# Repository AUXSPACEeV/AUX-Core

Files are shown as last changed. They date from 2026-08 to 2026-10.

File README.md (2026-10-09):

# `AUX-Core`

> Core/Sensor PCB of the Auxspace Avionics stack, built around an ESP32-S3-WROOM-1.

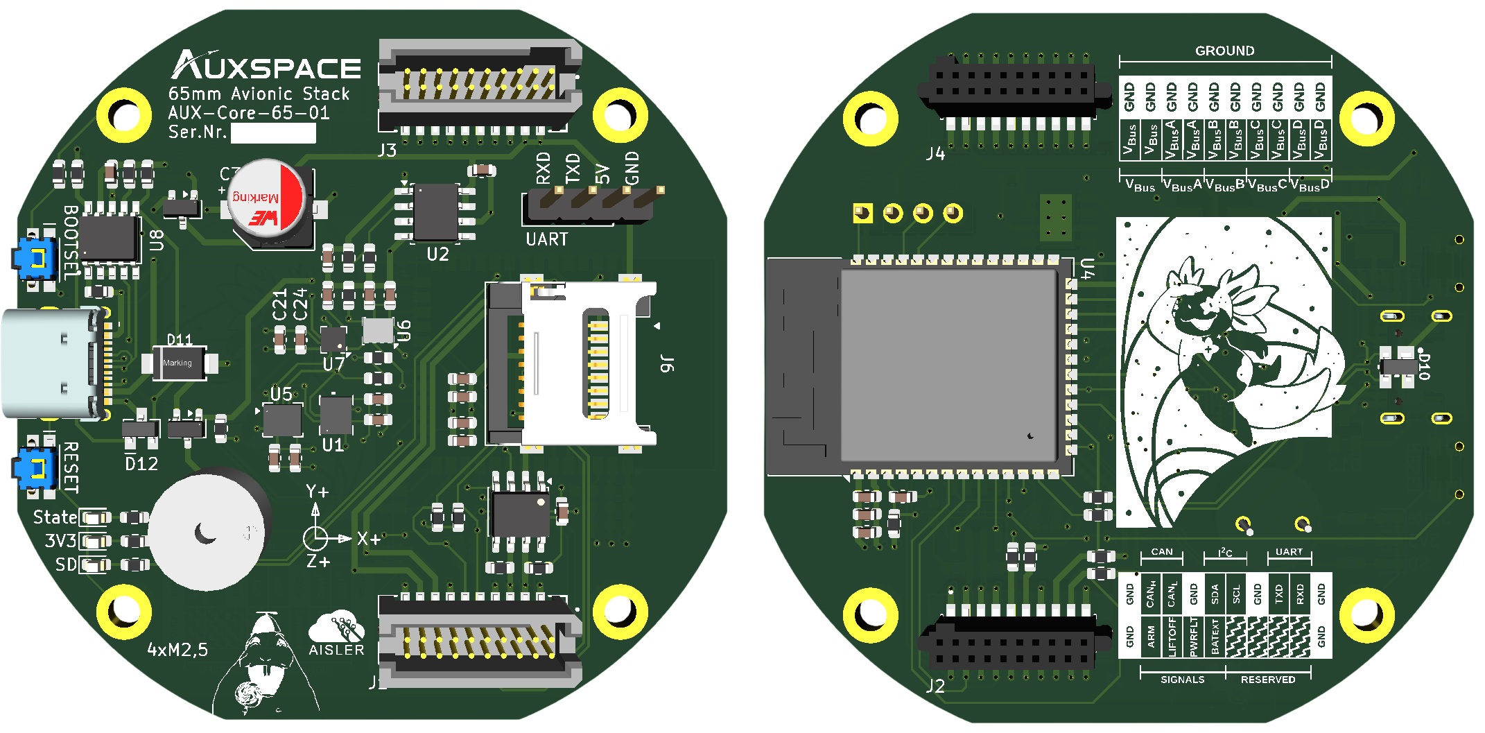
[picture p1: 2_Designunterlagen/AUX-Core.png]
pcb_cover,png


AUX-Core is our first stackable flight computer.
It operates on a powerful ESP32S3 MCU with sensors for attitude tracking,
9V USB Power Delivery or an external Power source and can interface
with other Auxspace Avionics stack components, such as
[AUX-Pwr](https://github.com/AUXSPACEeV/AUX-Pwr) or
[AUX-Tel](https://github.com/AUXSPACEeV/AUX-Tel).

## Features

* **Barometer** DPS310/DPS368 for altitude computation
* **IMU** STM LSM6DSO32x for acceleration and rotation data
* **High-G accelerometer** STM LSM6DSV320XTR (±320 g) when things get tough
* **Magnetometer** STM LIS3MDL for attitude reference
* **Buzzer** for easier commissioning and recovery
* **CAN bus** (TCAN334) for communication with the other stack PCBs
* **µSD card** for logging
* **USB-C with 9 V Power Delivery** (CH224A sink) for programming, debugging and supply
* **Stack connector** Samtec TFM-110-02-S-D-A / SFM-110-02-L-D-A for the avionics stack
* **Status LEDs** for power, SD activity and board state

## Stack connector

The board carries a mating Samtec pin/socket pair (2x10, 1.27 mm), so Core boards and
expansion PCBs stack directly on top of each other. The connector routes the switched and
unswitched VBus rails, CAN, I²C, UART and the ARM signal through the stack.

## Power supply

The board is supplied over USB-C. The CH224A PD sink negotiates 9 V from the charger; the
on-board TPS7B8601 regulator derives the 3V3 rail from it. VBus is distributed to the stack
both directly and through the switched rails.

## Programming

The ESP32-S3 is programmed via USB-C or the UART connection.
To enter download mode, press and hold BOOTSEL at startup.

## Repository layout

| Folder | Content |
| --- | --- |
| [`1_Blockschaltbild`](./1_Blockschaltbild) | Block diagrams |
| [`2_Designunterlagen`](./2_Designunterlagen) | Pin maps, calculations and design documents |
| [`3_Elektronik`](./3_Elektronik) | KiCad project, symbols, footprints and 3D models  |
| [`4_Simulationen`](./4_Simulationen) | LTspice simulations |
| [`5_Tests`](./5_Tests) | Test results and oscillograms |
| [`6_Export-Fertigungsdaten`](./6_Export-Fertigungsdaten) | Manufacturing data, BOMs, schematics and STEP files |

## License

Hardware is released under the CERN Open Hardware Licence Version 2 - Permissive,
see [`LICENSE`](./LICENSE).

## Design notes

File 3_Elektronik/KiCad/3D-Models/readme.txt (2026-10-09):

Notes:
 
1. All drill sizes are the maximum size provided by the manufacture (as required to calculate the minimum pad size).
2. All dimensions in building footprints are the maximum (including any tolerance) as defined by the manufacturer with the exception of row pitch (which is always nominal).  If only the normal sizing is provided we will input that dimension in mils, rounded to the nearest mil per our standards.
3. Slots are currently identified as entities describing the size of the slot (arcs, lines, etc.) on the board outline layer.  The extremities are identified with a via at each end.  These slots will either need to be:
	a. identified and dimensioned on your fabrication document
	b. or they will need to be converted to slots (assuming the targeted tool has a slot capability) using the process defined in your cad tool for identifying a padstack as a slot.  
		i. Typically this is only capable of a width and length of the slot and a size of the mill radius that creates the slot.  
		ii. Choosing to use the native tool slots will require removing entities on the board outline and the associated pads in the footprint.

Attribution:

Symbols, footprints and 3D models of Würth Elektronik parts (files named *Wurth*, *Würth*, *Wuerth*, WE-* and
the matching entries in AUXSPACE.kicad_sym / AUXSPACE.pretty, e.g. the WS-TASU, WS-TASV, WR-CRD,
WR-USB, WR-WTB, WCAP-ASLL and WE-TVS libraries) are © Würth Elektronik eiSos GmbH & Co. KG, https://www.we-online.com,
and are licensed under the Creative Commons Attribution-ShareAlike 4.0 International License
(https://creativecommons.org/licenses/by-sa/4.0/). Changes made for this project: converted to the current KiCad file
format, merged into the AUXSPACE libraries, and footprint/3D-model paths and footprint links adapted.

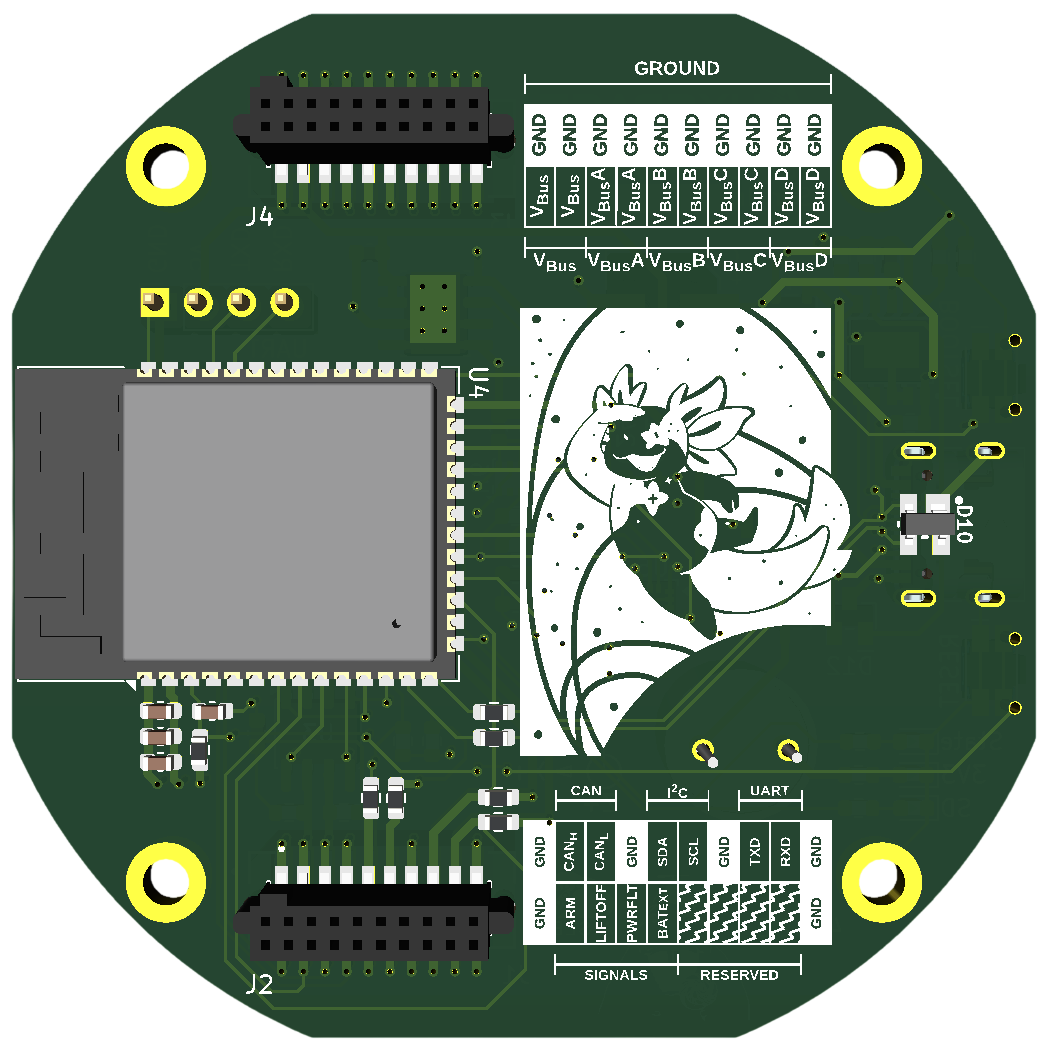
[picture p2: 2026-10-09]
6_Export-Fertigungsdaten/rev-01/AUXSPACE_core_pcb_back.png

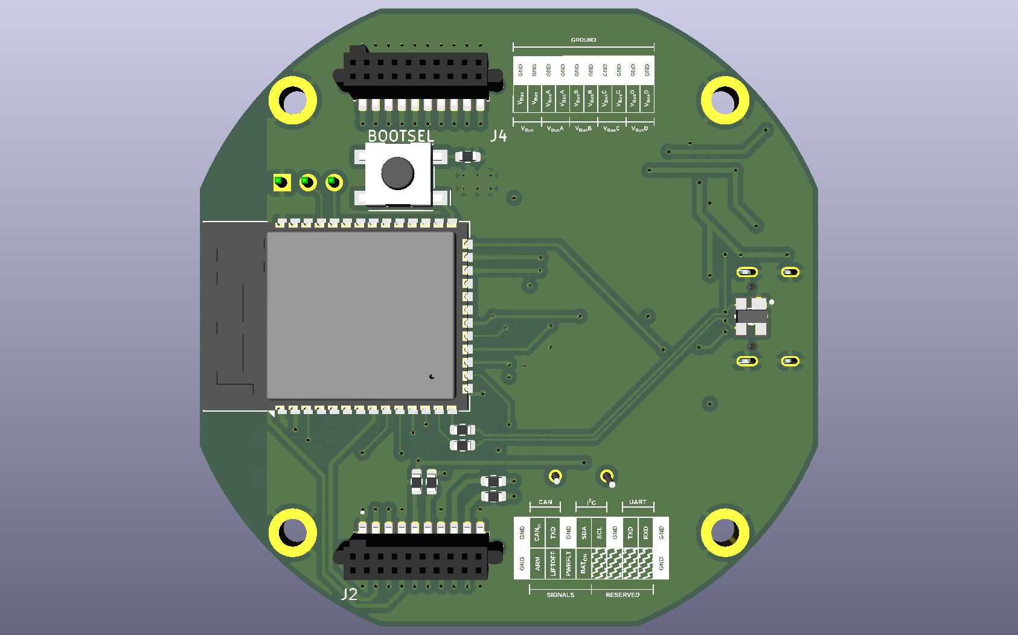
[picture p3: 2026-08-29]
6_Export-Fertigungsdaten/rev-cansta-alpha/AUXSPACE_core_pcb_back.png

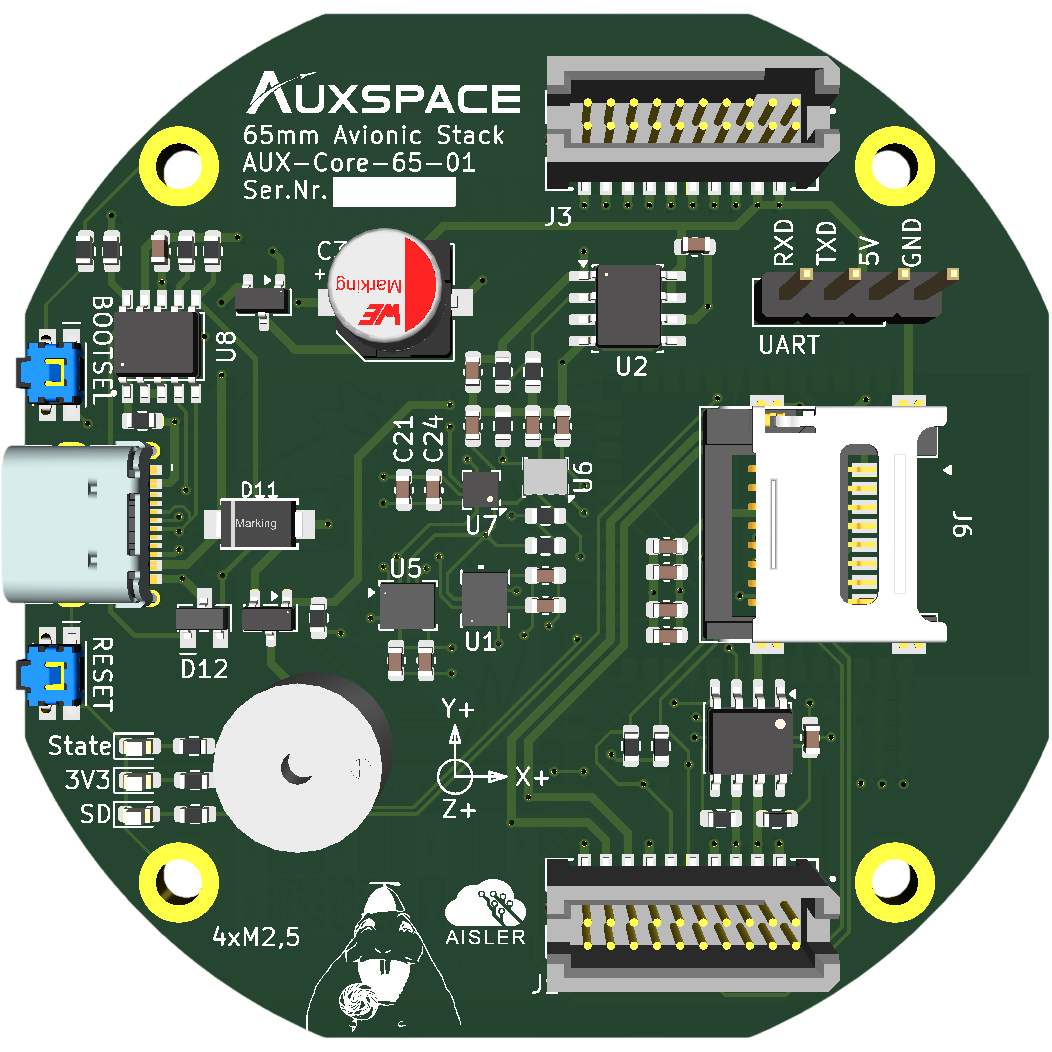
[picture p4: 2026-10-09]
6_Export-Fertigungsdaten/rev-01/AUXSPACE_core_pcb_front.png

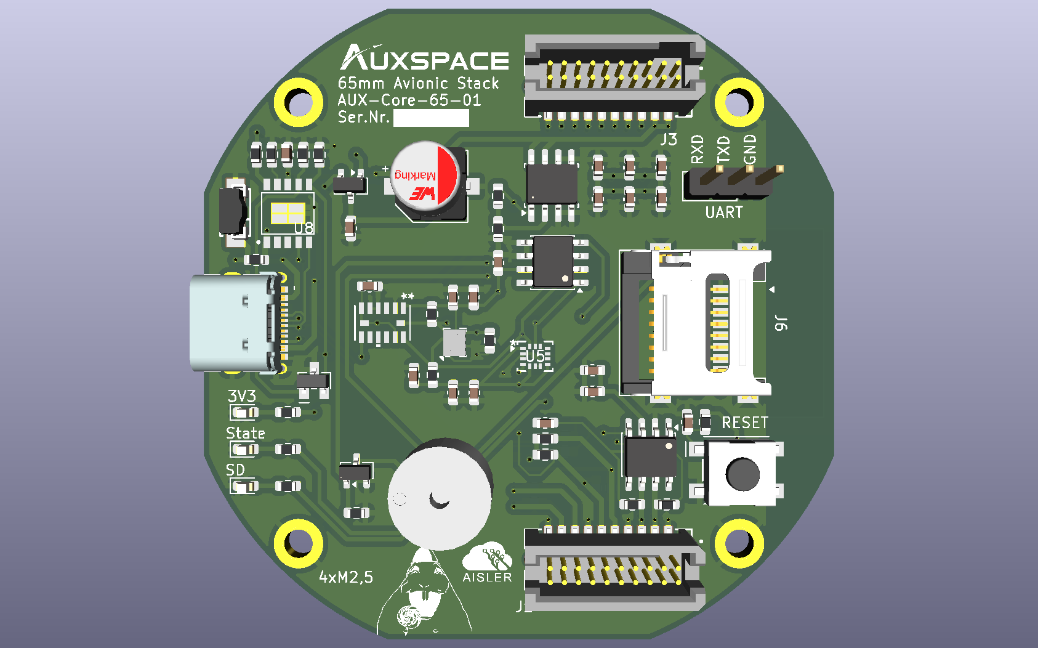
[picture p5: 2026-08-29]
6_Export-Fertigungsdaten/rev-cansta-alpha/AUXSPACE_core_pcb_front.png

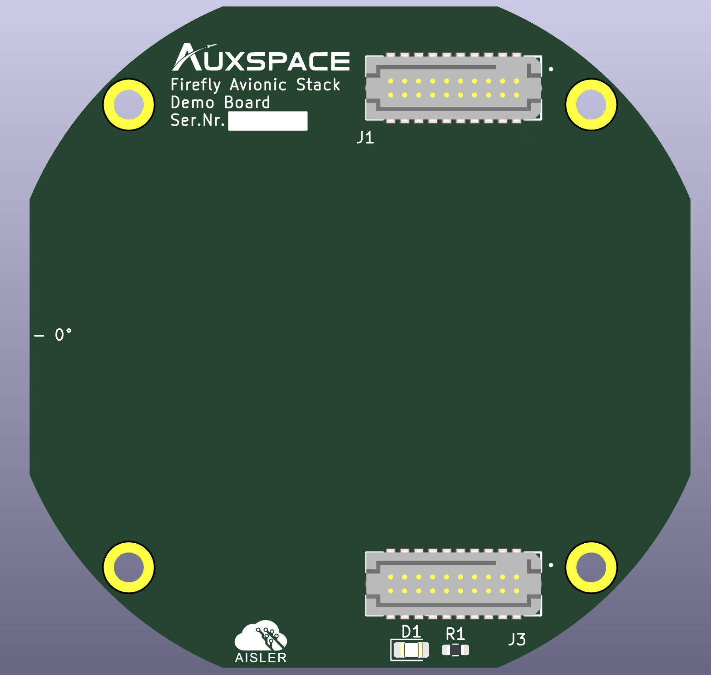
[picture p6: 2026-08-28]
3_Elektronik/KiCad/meta/brd.png

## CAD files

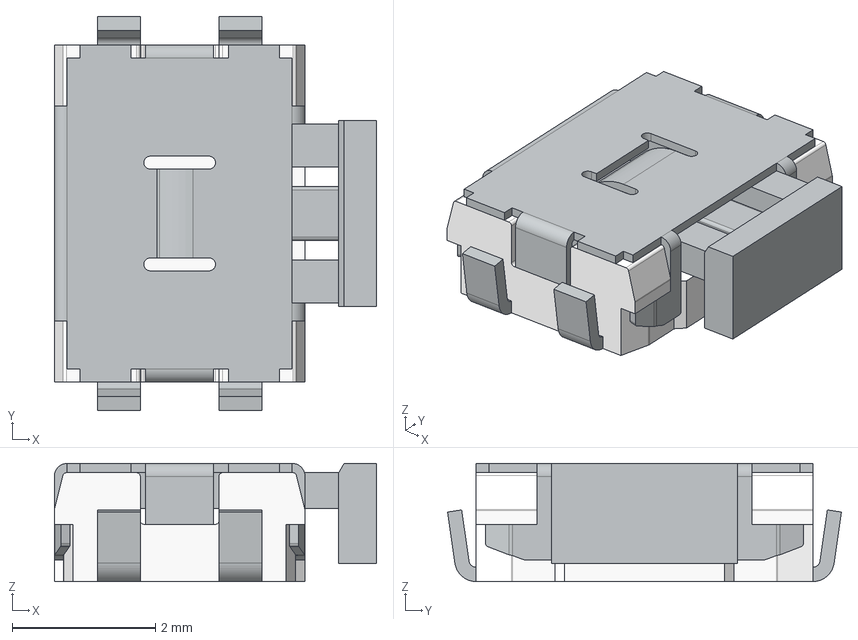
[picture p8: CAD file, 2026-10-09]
3_Elektronik/KiCad/3D-Models/SW_Wurth_WS-TASU_4343X30458XX.step
4.50 x 5.50 x 1.65 mm

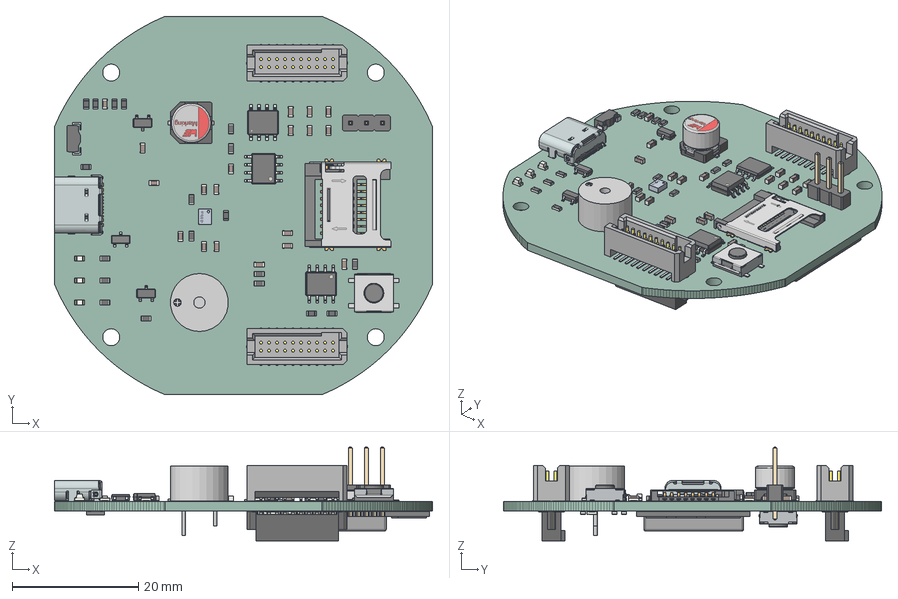
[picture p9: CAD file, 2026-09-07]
6_Export-Fertigungsdaten/rev-01/Aux-core.step
60.0 x 60.0 x 14.9 mm
R_0603_1608Metric x 26
C_0603_1608Metric x 19
CP_Wurth_WCAP-ASLL-D6.3L5.5
1_transformed
LED_0603_1608Metric x 3
SOT-23 x 2
SOIC-8_3.9x4.9mm_P1.27mm x 2
PinHeader_1x03_P254mm_Vertical
SMAJ-ALL
WST-0906T v2
Texas_HTSOP-8-1EP_3.9x4.9mm_P1.27mm_EP2.95x4.9mm_Mask2.4x3.1mm_ ThermalVias
693072010801_PIN x 8
693072010801_PATTE x 3
693072010801_CACHE
693072010801_PATTE_SPE
SW_Wurth_WS-TASV_430481025816 x 2
CADSOFTTOOLS 2.1
CADSOFTTOOLS 2.2
CADSOFTTOOLS 2.3
CADSOFTTOOLS 2.4
CADSOFTTOOLS 2.5
CADSOFTTOOLS 2.6
CADSOFTTOOLS 2.7
CADSOFTTOOLS 2.8
CADSOFTTOOLS 2.9
CADSOFTTOOLS 2.10
CADSOFTTOOLS 2.11
CADSOFTTOOLS 2.12
CADSOFTTOOLS 2.13
CADSOFTTOOLS 2.14
CADSOFTTOOLS 2.15
CADSOFTTOOLS 2.16
CADSOFTTOOLS 2.17
CADSOFTTOOLS 2.18
CADSOFTTOOLS 2.19
CADSOFTTOOLS 2.20
CADSOFTTOOLS 2.21
CADSOFTTOOLS 2.22
CADSOFTTOOLS 2.23
CADSOFTTOOLS 2.24
CADSOFTTOOLS 2.25
CADSOFTTOOLS 2.26
CADSOFTTOOLS 2.27
CADSOFTTOOLS 2.28
CADSOFTTOOLS 2.29
CADSOFTTOOLS 2.30
CADSOFTTOOLS 2.31
CADSOFTTOOLS 2.32
CADSOFTTOOLS 2.33
CADSOFTTOOLS 2.34
CADSOFTTOOLS 2.35
CADSOFTTOOLS 2.36
CADSOFTTOOLS 2.37
CADSOFTTOOLS 2.38
CADSOFTTOOLS 2.39
CADSOFTTOOLS 2.40
CADSOFTTOOLS 2.41
CADSOFTTOOLS 2.42
CADSOFTTOOLS 2.43
CADSOFTTOOLS 2.44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

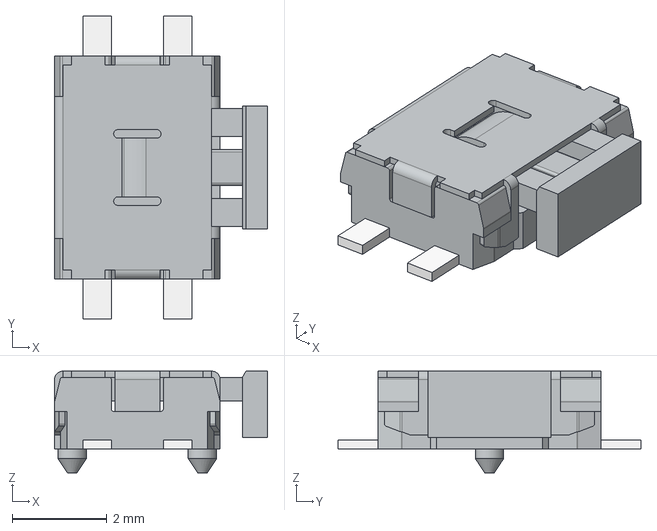
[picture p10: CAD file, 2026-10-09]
3_Elektronik/KiCad/3D-Models/SW_Wurth_WS-TASU_4363X10458XX.step
4.50 x 6.40 x 2.15 mm

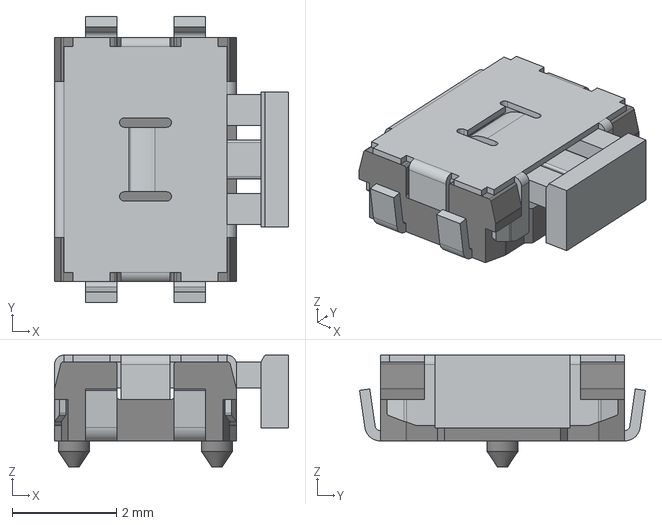
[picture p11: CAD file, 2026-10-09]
3_Elektronik/KiCad/3D-Models/SW_Wurth_WS-TASU_4363X30458XX.step
4.50 x 5.50 x 2.15 mm

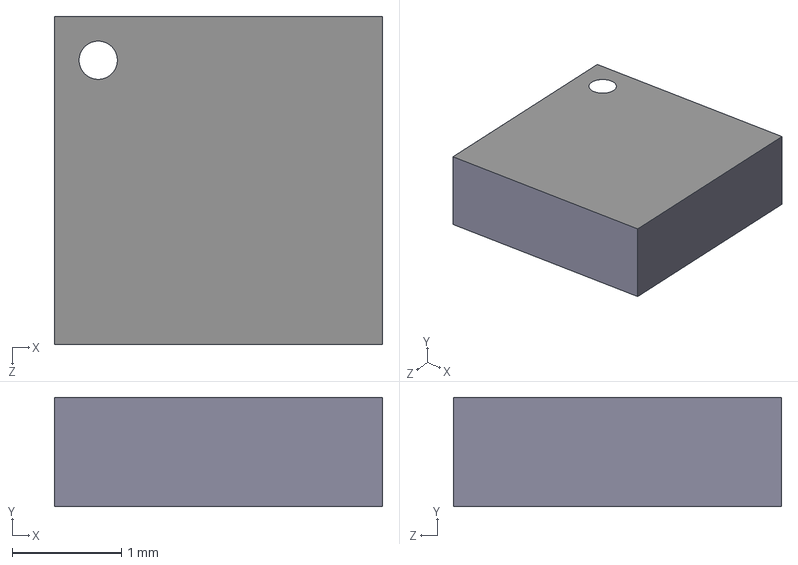
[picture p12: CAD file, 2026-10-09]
3_Elektronik/KiCad/3D-Models/IST8310.step
3.00 x 1.00 x 3.00 mm

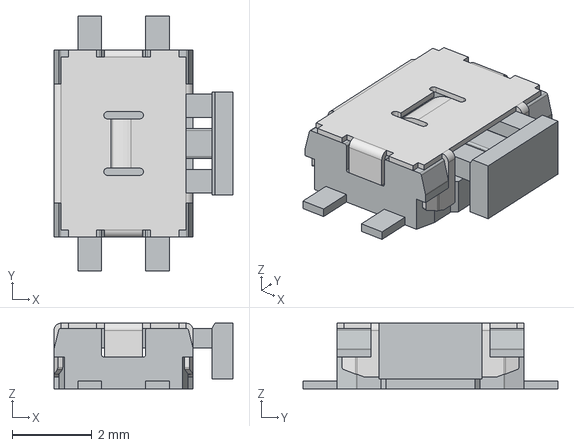
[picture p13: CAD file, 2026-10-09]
3_Elektronik/KiCad/3D-Models/SW_Wurth_WS-TASU_4343X10458XX.step
4.50 x 6.40 x 1.65 mm

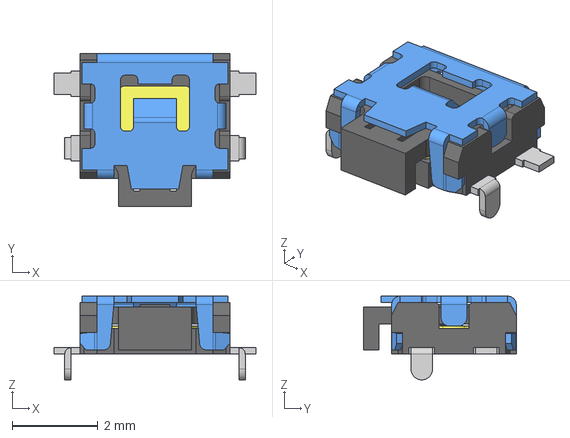
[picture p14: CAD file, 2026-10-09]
3_Elektronik/KiCad/3D-Models/SW_Wurth_WS-TASU_434331013822.step
4.70 x 3.55 x 1.95 mm

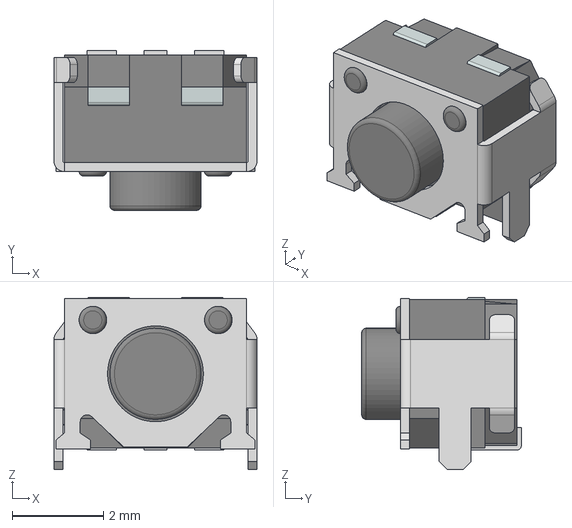
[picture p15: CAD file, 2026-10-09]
3_Elektronik/KiCad/3D-Models/SW_Wurth_WS-TASU_436333033816.step
4.45 x 3.50 x 3.78 mm

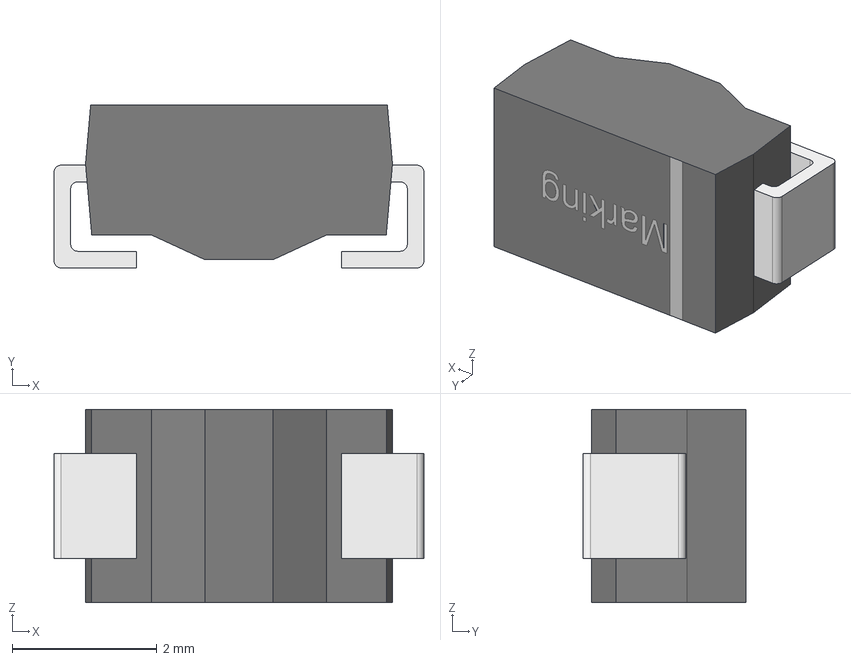
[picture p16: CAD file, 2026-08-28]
3_Elektronik/KiCad/3D-Models/WE-TVS_SMAJ22A.stp
5.11 x 2.25 x 2.67 mm

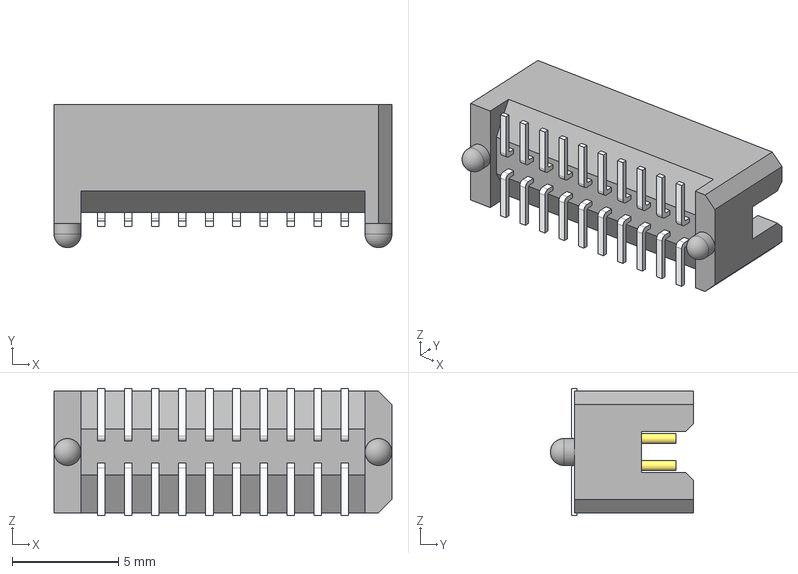
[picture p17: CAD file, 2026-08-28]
3_Elektronik/KiCad/3D-Models/TFM-110-02-S-D-A.stp
15.9 x 6.73 x 5.97 mm
TFM-110-02-L-D-A_terminal
TFM-110-02-L-D-L_pins
TFM-110-02-L-D-S-2_pins

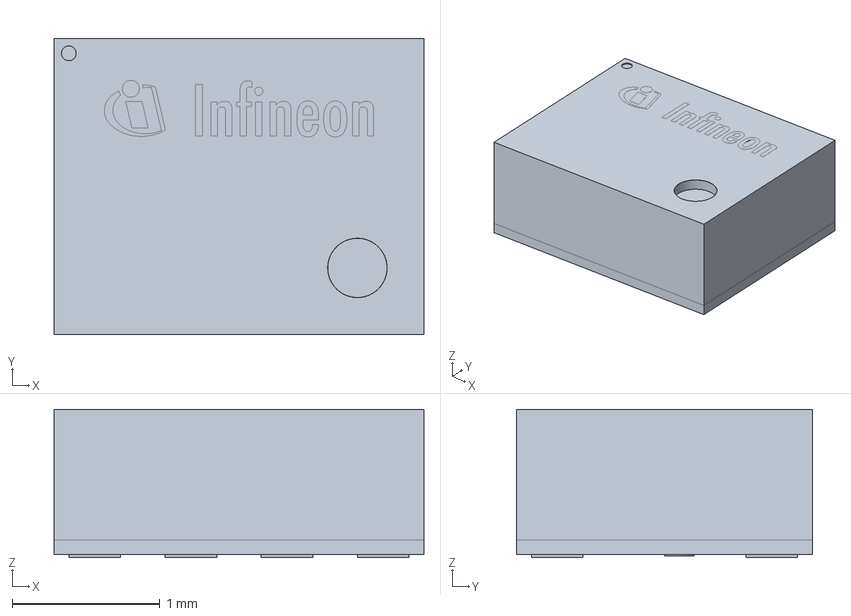
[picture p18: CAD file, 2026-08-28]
3_Elektronik/KiCad/3D-Models/DPS310XTSA1.stp
2.50 x 2.00 x 1.00 mm
CADSOFTTOOLS 2.1
CADSOFTTOOLS 2.2
CADSOFTTOOLS 2.3
CADSOFTTOOLS 2.4
CADSOFTTOOLS 2.5
CADSOFTTOOLS 2.6
CADSOFTTOOLS 2.7
CADSOFTTOOLS 2.8
CADSOFTTOOLS 2.9
CADSOFTTOOLS 2.10
CADSOFTTOOLS 2.11
CADSOFTTOOLS 2.12
CADSOFTTOOLS 2.13
CADSOFTTOOLS 2.14
CADSOFTTOOLS 2.15
CADSOFTTOOLS 2.16
CADSOFTTOOLS 2.17
CADSOFTTOOLS 2.18
CADSOFTTOOLS 2.19
CADSOFTTOOLS 2.20
CADSOFTTOOLS 2.21
CADSOFTTOOLS 2.22
CADSOFTTOOLS 2.23
CADSOFTTOOLS 2.24
CADSOFTTOOLS 2.25
CADSOFTTOOLS 2.26
CADSOFTTOOLS 2.27
CADSOFTTOOLS 2.28
CADSOFTTOOLS 2.29
CADSOFTTOOLS 2.30
CADSOFTTOOLS 2.31
CADSOFTTOOLS 2.32
CADSOFTTOOLS 2.33
CADSOFTTOOLS 2.34
CADSOFTTOOLS 2.35
CADSOFTTOOLS 2.36
CADSOFTTOOLS 2.37
CADSOFTTOOLS 2.38
CADSOFTTOOLS 2.39
CADSOFTTOOLS 2.40
CADSOFTTOOLS 2.41
CADSOFTTOOLS 2.42
CADSOFTTOOLS 2.43
CADSOFTTOOLS 2.44
CADSOFTTOOLS 2.45
CADSOFTTOOLS 2.46
CADSOFTTOOLS 2.47
CADSOFTTOOLS 2.48
CADSOFTTOOLS 2.49
CADSOFTTOOLS 2.50
CADSOFTTOOLS 2.51
CADSOFTTOOLS 2.52
CADSOFTTOOLS 2.53
CADSOFTTOOLS 2.54
CADSOFTTOOLS 2.55
CADSOFTTOOLS 2.56
CADSOFTTOOLS 2.57
CADSOFTTOOLS 2.58
CADSOFTTOOLS 2.59
CADSOFTTOOLS 2.60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

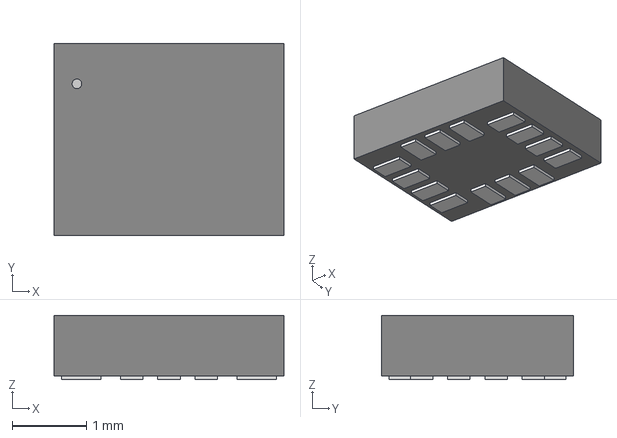
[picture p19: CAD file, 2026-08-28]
3_Elektronik/KiCad/3D-Models/LGA_O32XTR_STM.step
3.10 x 2.59 x 0.866 mm

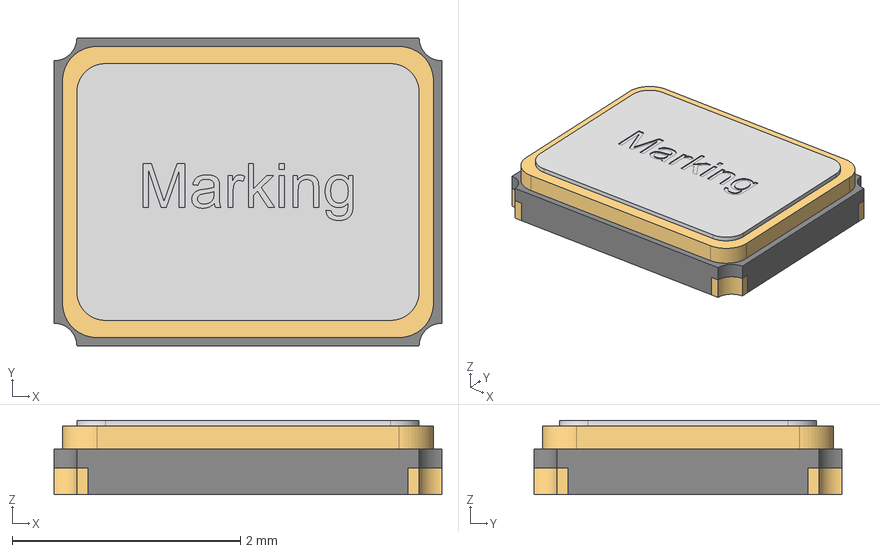
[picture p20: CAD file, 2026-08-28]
3_Elektronik/KiCad/3D-Models/wurth_Crystal_830105420809 (rev1).stp
3.40 x 2.70 x 0.65 mm
Pins
Cover

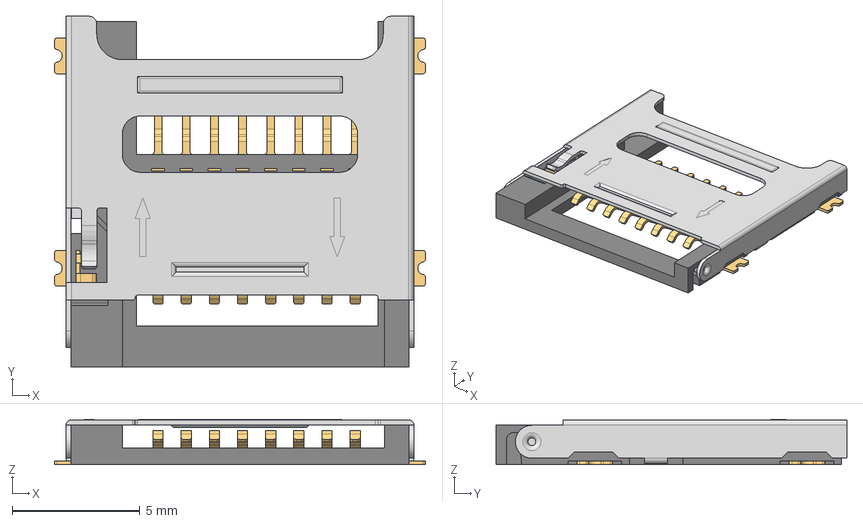
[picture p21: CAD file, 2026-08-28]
3_Elektronik/KiCad/3D-Models/J_Wurth_WR-CRD_693072010801.step
14.5 x 13.7 x 1.77 mm
693072010801_PIN x 8
693072010801_PATTE x 3
693072010801_CACHE
693072010801_PATTE_SPE

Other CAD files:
3_Elektronik/KiCad/3D-Models/J_Wurth_WR-WTB_61900211121.step
3_Elektronik/KiCad/3D-Models/WE-TVS-HS_SOT143-4L_8240136.step
3_Elektronik/KiCad/3D-Models/USBC-Würth_632723100011.step
3_Elektronik/KiCad/3D-Models/Buzzer_WST-0906T.step
3_Elektronik/KiCad/3D-Models/CP_Wurth_WCAP-ASLL-D6.3L5.5.step
3_Elektronik/KiCad/3D-Models/J_Wurth_WR-USB_629722000214.step
3_Elektronik/KiCad/3D-Models/SFM-110-02-L-D-A.stp
3_Elektronik/KiCad/3D-Models/SW_Wurth_WS-TASU_434381035816.step
3_Elektronik/KiCad/3D-Models/SW_Wurth_WS-TASV_430481025816.step
3_Elektronik/KiCad/3D-Models/Texas_HSOP-8_3.9x4.9mm_EP2.95x4.9mm.step
3_Elektronik/KiCad/3D-Models/WE-TVS_824094024_SOT23-3L.step
3_Elektronik/KiCad/3D-Models/WE_693071020811 (rev1).stp

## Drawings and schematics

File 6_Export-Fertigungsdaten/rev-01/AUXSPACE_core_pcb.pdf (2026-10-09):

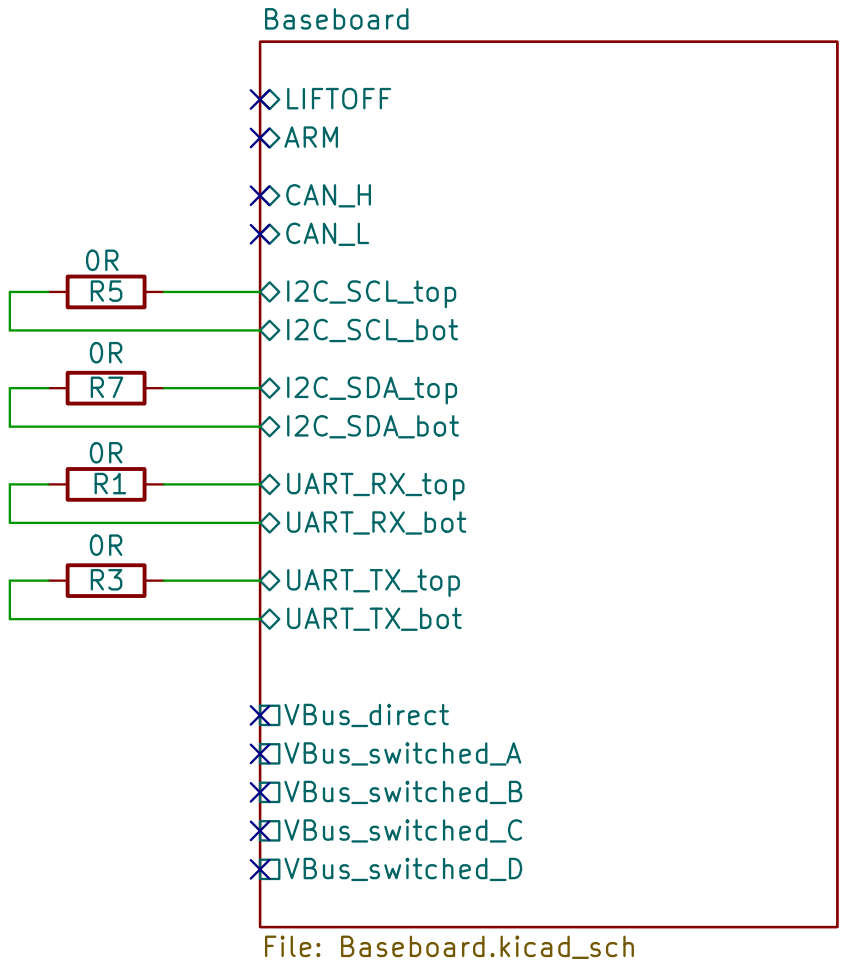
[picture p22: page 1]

Size: A3 | Rev: | F Date:
KiCad E.D.A. 10.0.7 | Id: 1/2

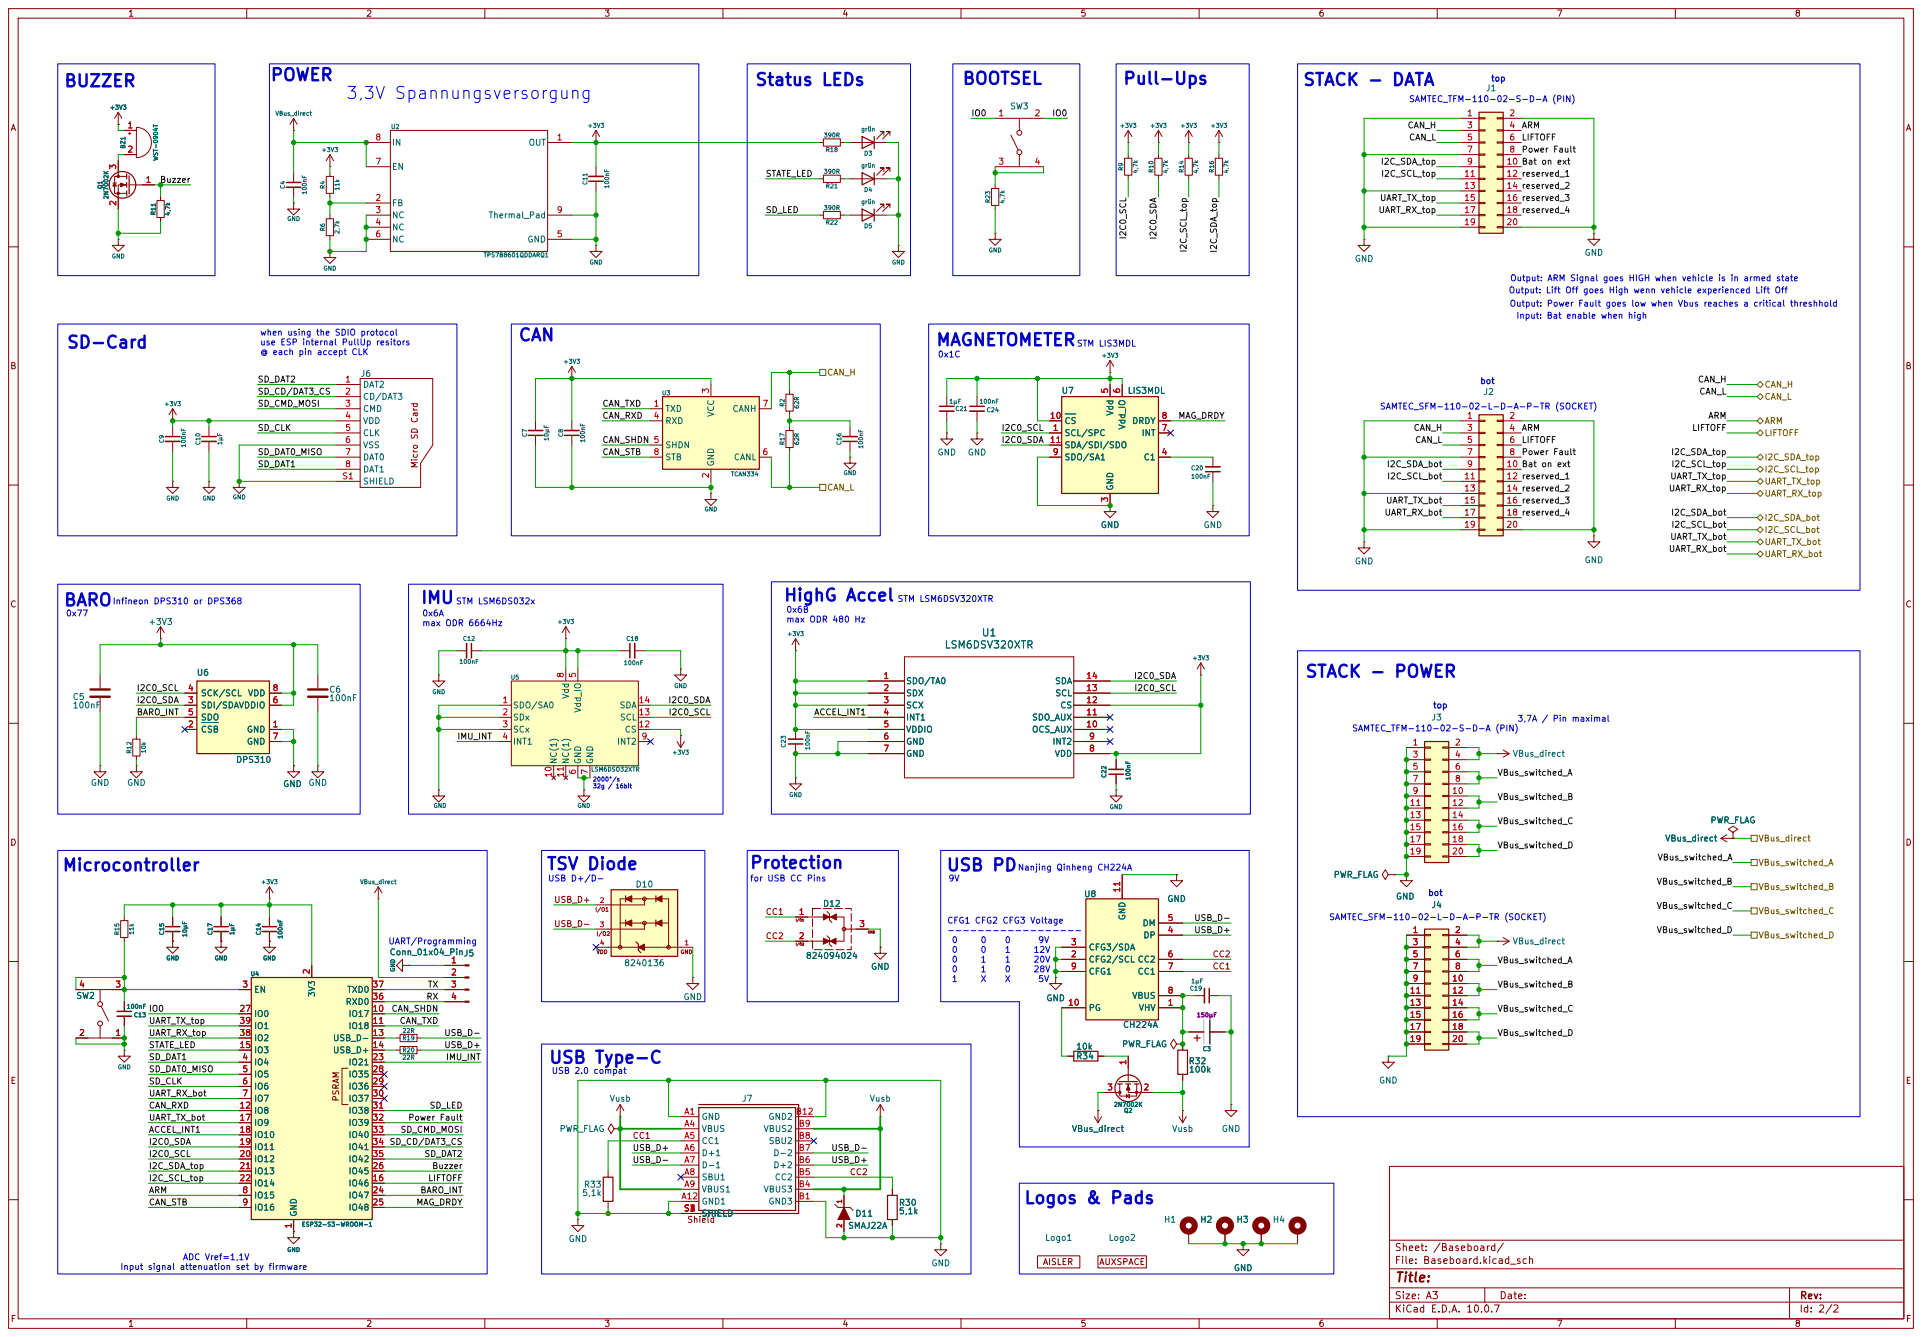
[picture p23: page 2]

when using the SDIO protocol use ESP internal PullUp resitors @ each pin accept CLK BUZZER

Input: Bat enable when high SAMTEC_SFM-110-02-L-D-A-P-TR (SOCKET) STM LIS3MDL BOOTSEL
UART_RX_top CAN_L

Output: ARM Signal goes HIGH when vehicle is in armed state TSV Diode

Output: Power Fault goes low when Vbus reaches a critical threshhold 9V Protection

3,7A / Pin maximal HighG Accel
I2C0_SDA USB_D+

USB PD Nanjing Qinheng CH224A STM LSM6DSV320XTR

9 | 10
11 | 12
13 | 14
15 | 16
17 | 18
19 | 20

7 7 | 8 8
9 9 | 10 10
11 11 | 12 12
13 13 | 14 14
15 15 | 16 16
17 17 | 18 18

Input signal attenuation set by firmware

Size: A3 | Rev: | F Date:
KiCad E.D.A. 10.0.7 | Id: 2/2

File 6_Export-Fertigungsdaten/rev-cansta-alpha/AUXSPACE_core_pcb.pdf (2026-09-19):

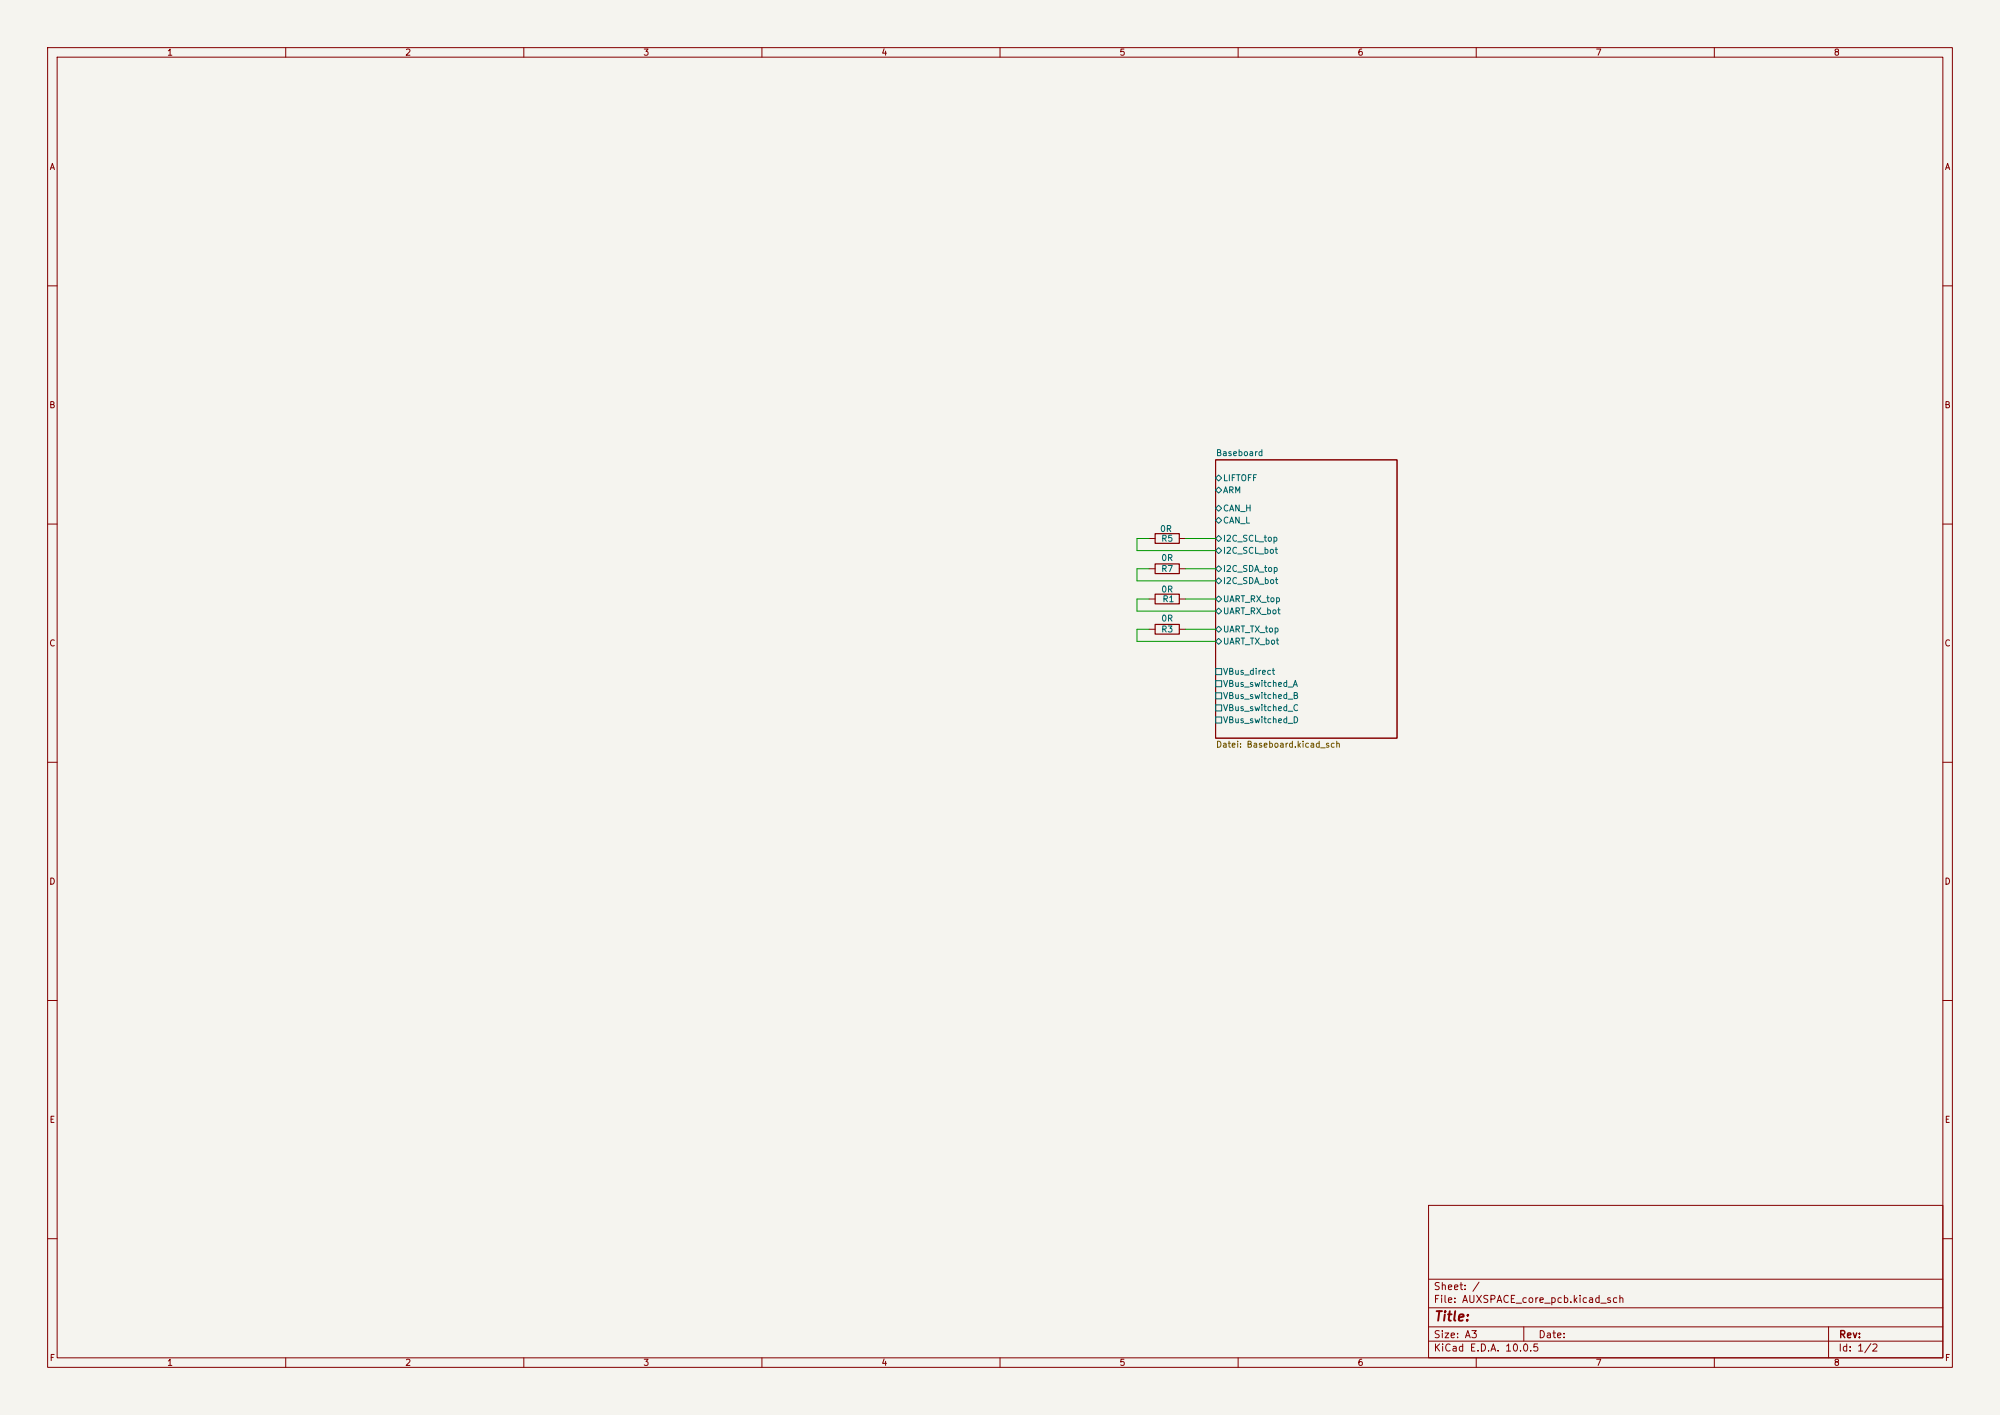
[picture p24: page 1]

Size: A3 | Rev: | F Date:
KiCad E.D.A. 10.0.5 | Id: 1/2

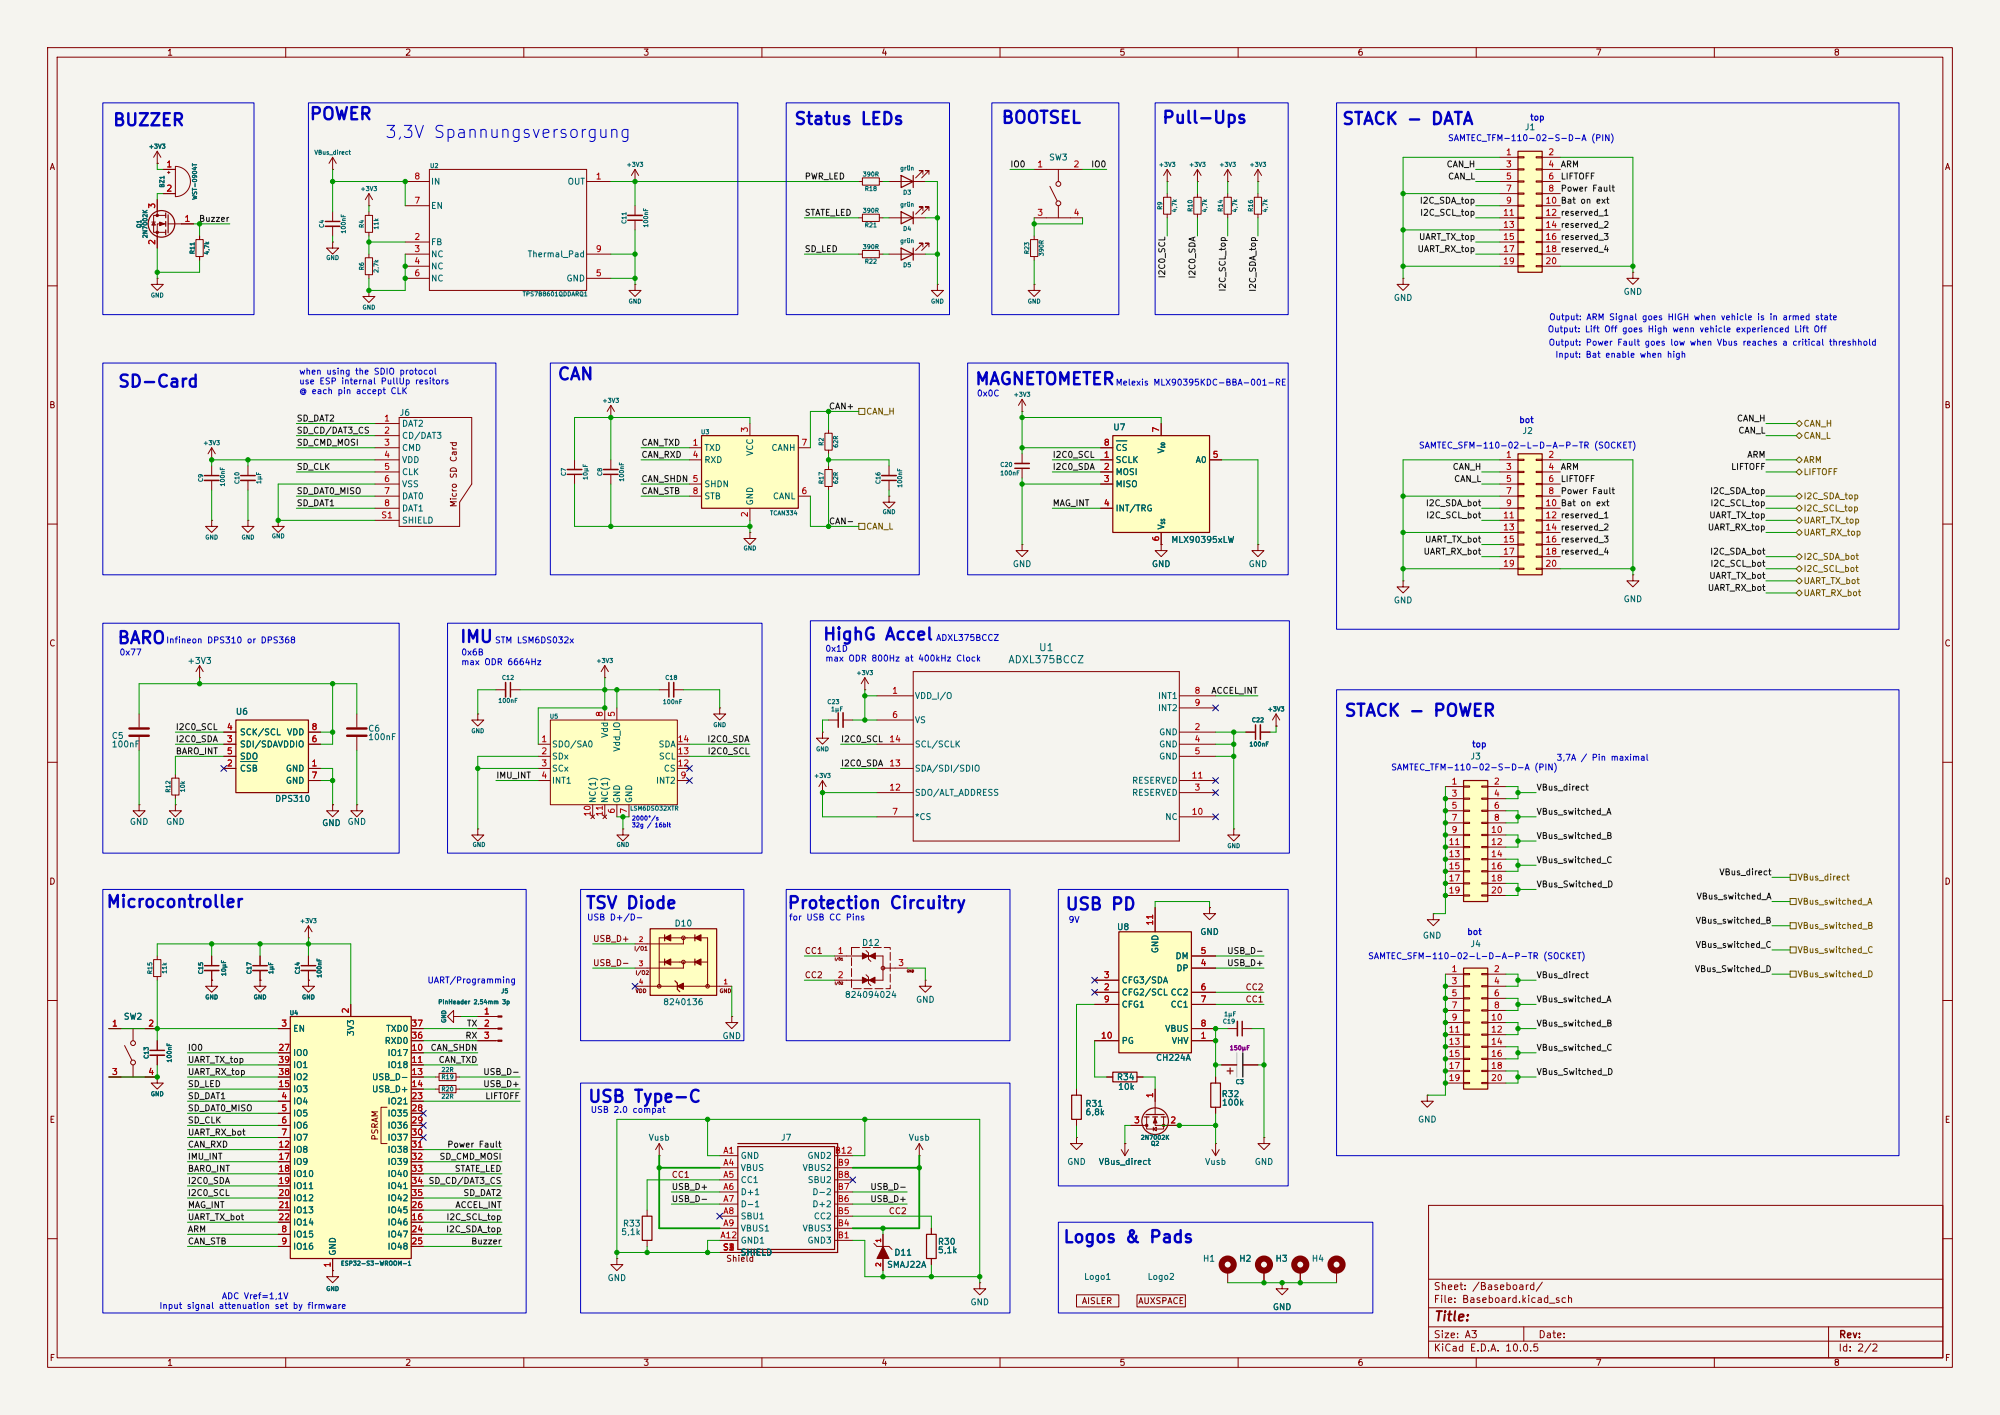
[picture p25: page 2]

Output: Power Fault goes low when Vbus reaches a critical threshhold 3,7A / Pin maximal

Input: Bat enable when high 0x77 BARO

when using the SDIO protocol use ESP internal PullUp resitors @ each pin accept CLK

LIFTOFF Power Fault ARM
LIFTOFF

9 | 10
11 | 12
13 | 14
15 | 16
17 | 18
19 | 20

Input signal attenuation set by firmware

Size: A3 | Rev: | F Date:
KiCad E.D.A. 10.0.5 | Id: 2/2

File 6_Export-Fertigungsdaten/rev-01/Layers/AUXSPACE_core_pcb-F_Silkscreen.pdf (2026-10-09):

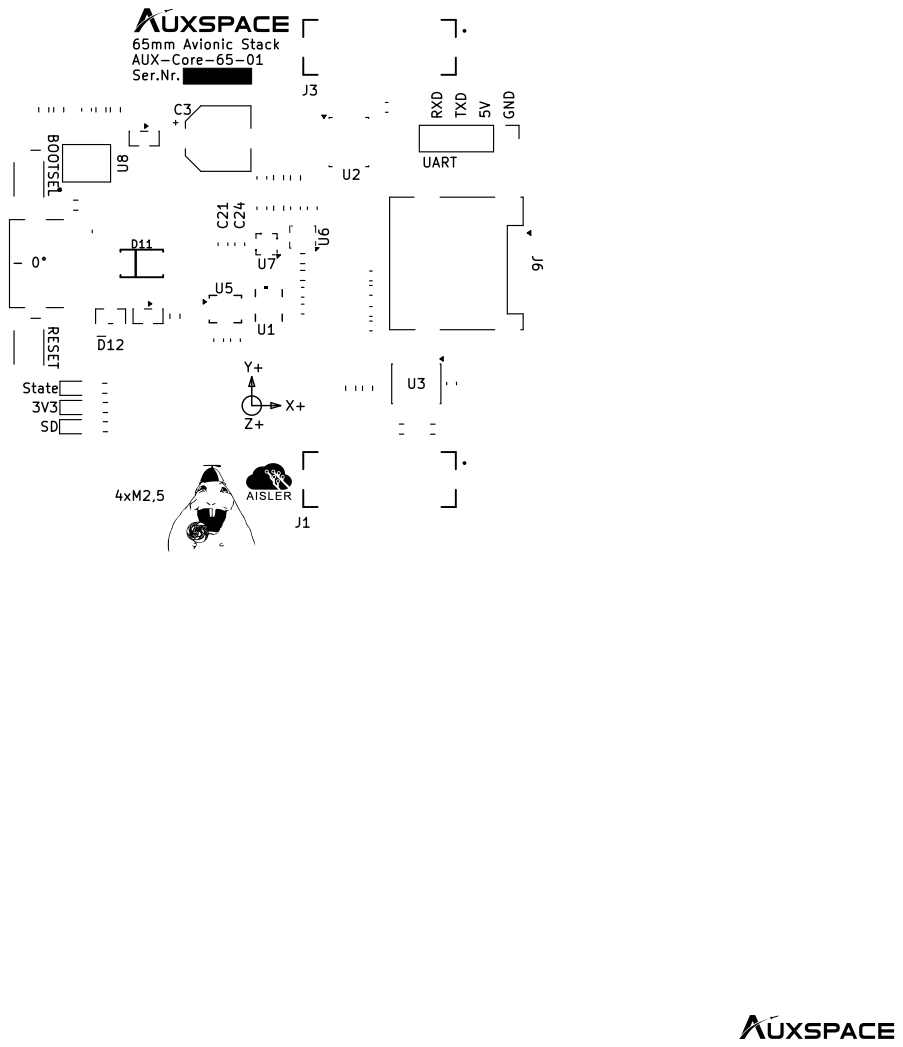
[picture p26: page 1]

65mm Avionic Stack AUX-Core-65-01

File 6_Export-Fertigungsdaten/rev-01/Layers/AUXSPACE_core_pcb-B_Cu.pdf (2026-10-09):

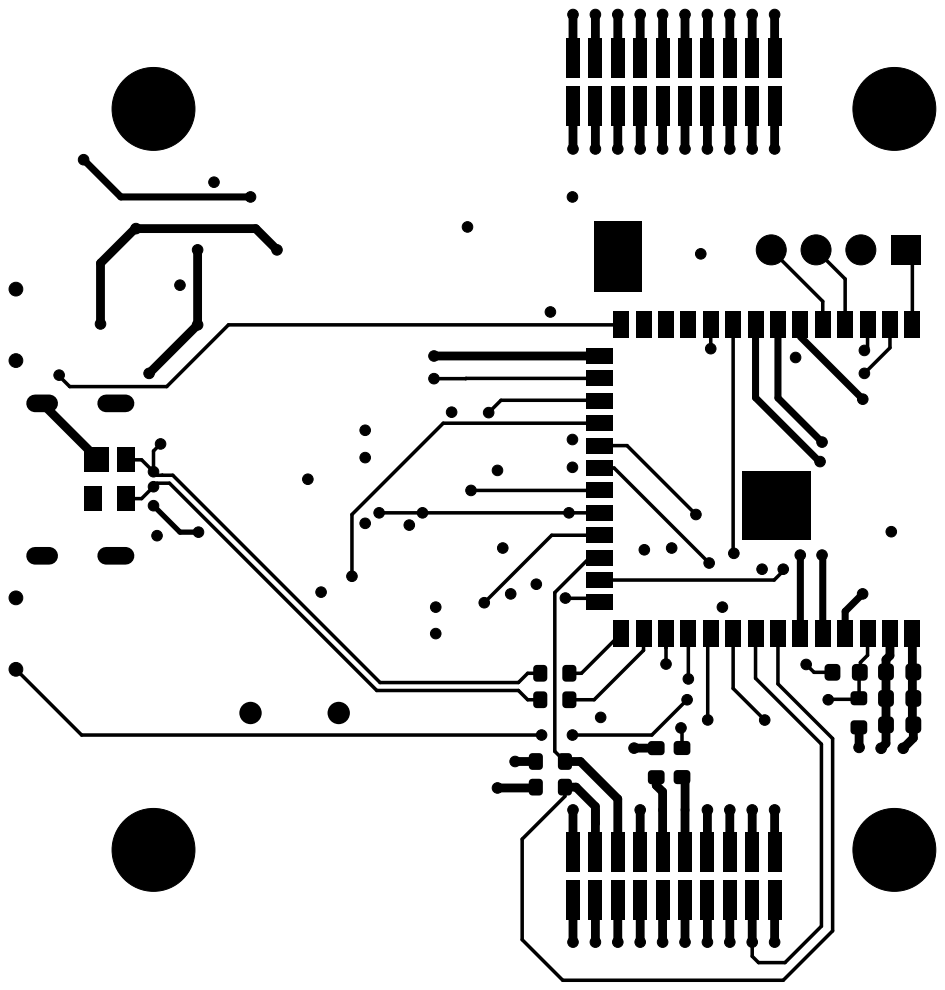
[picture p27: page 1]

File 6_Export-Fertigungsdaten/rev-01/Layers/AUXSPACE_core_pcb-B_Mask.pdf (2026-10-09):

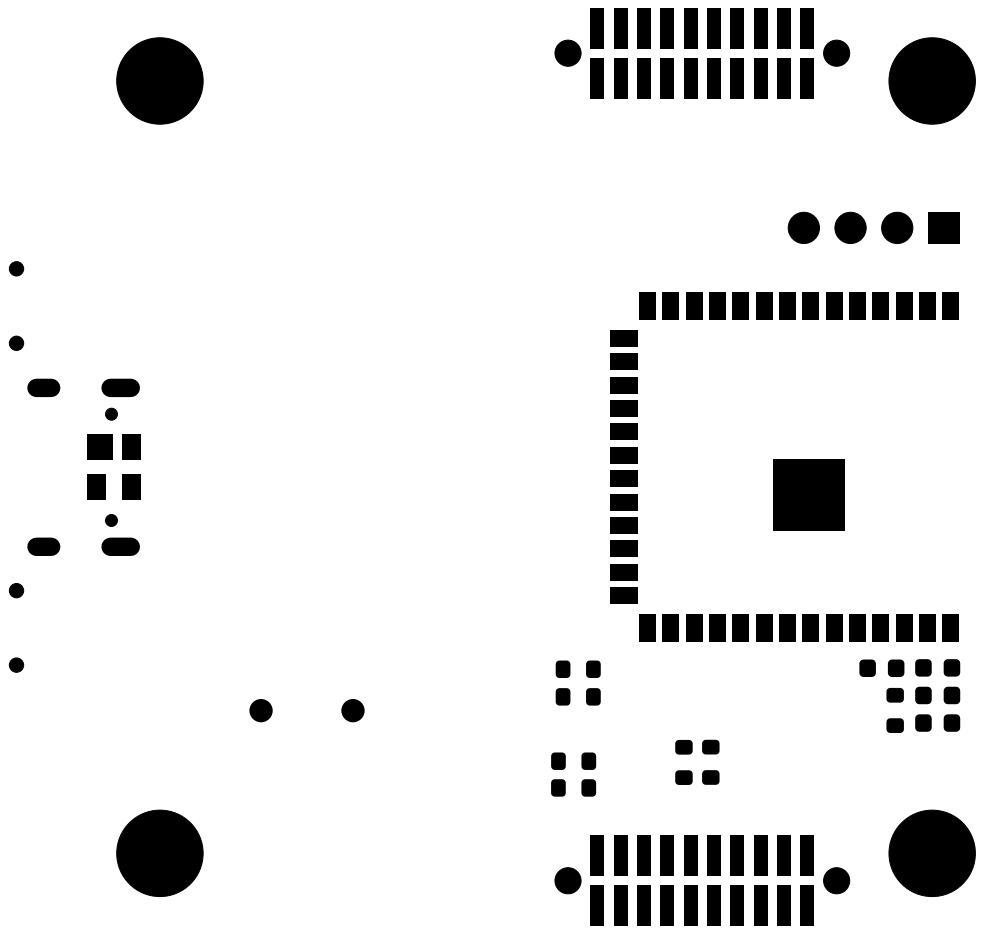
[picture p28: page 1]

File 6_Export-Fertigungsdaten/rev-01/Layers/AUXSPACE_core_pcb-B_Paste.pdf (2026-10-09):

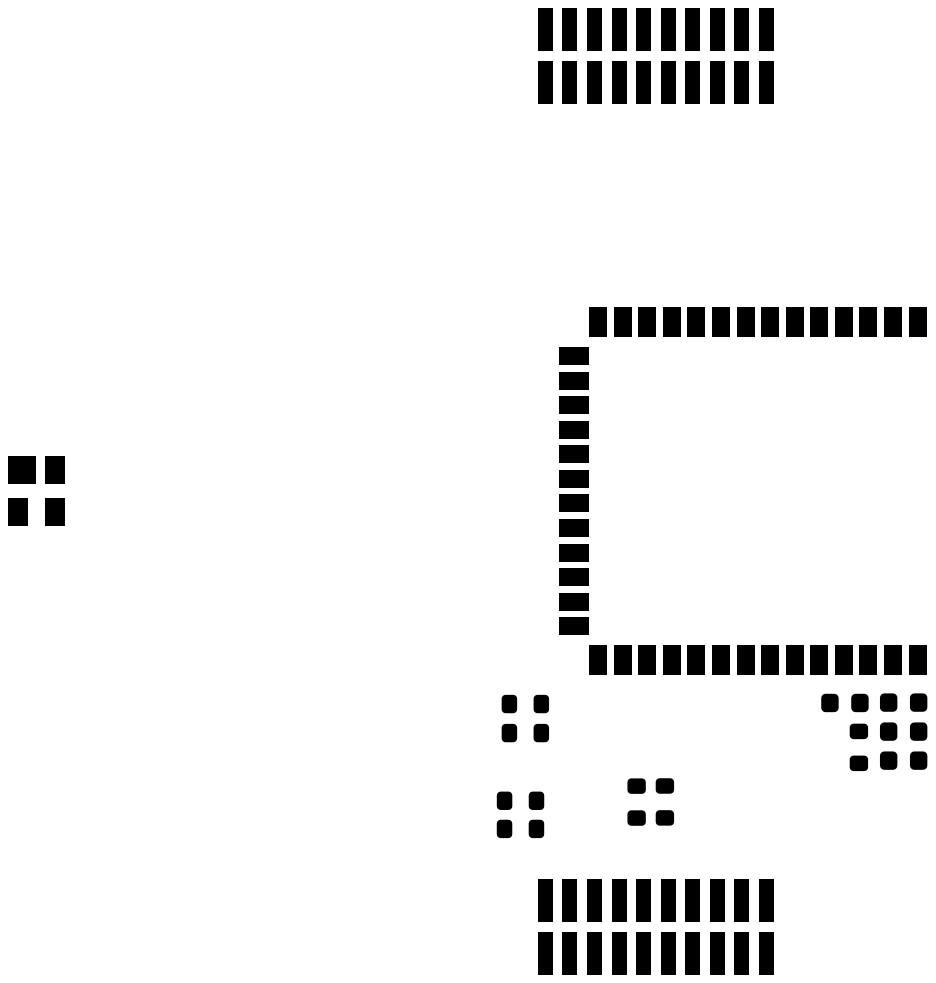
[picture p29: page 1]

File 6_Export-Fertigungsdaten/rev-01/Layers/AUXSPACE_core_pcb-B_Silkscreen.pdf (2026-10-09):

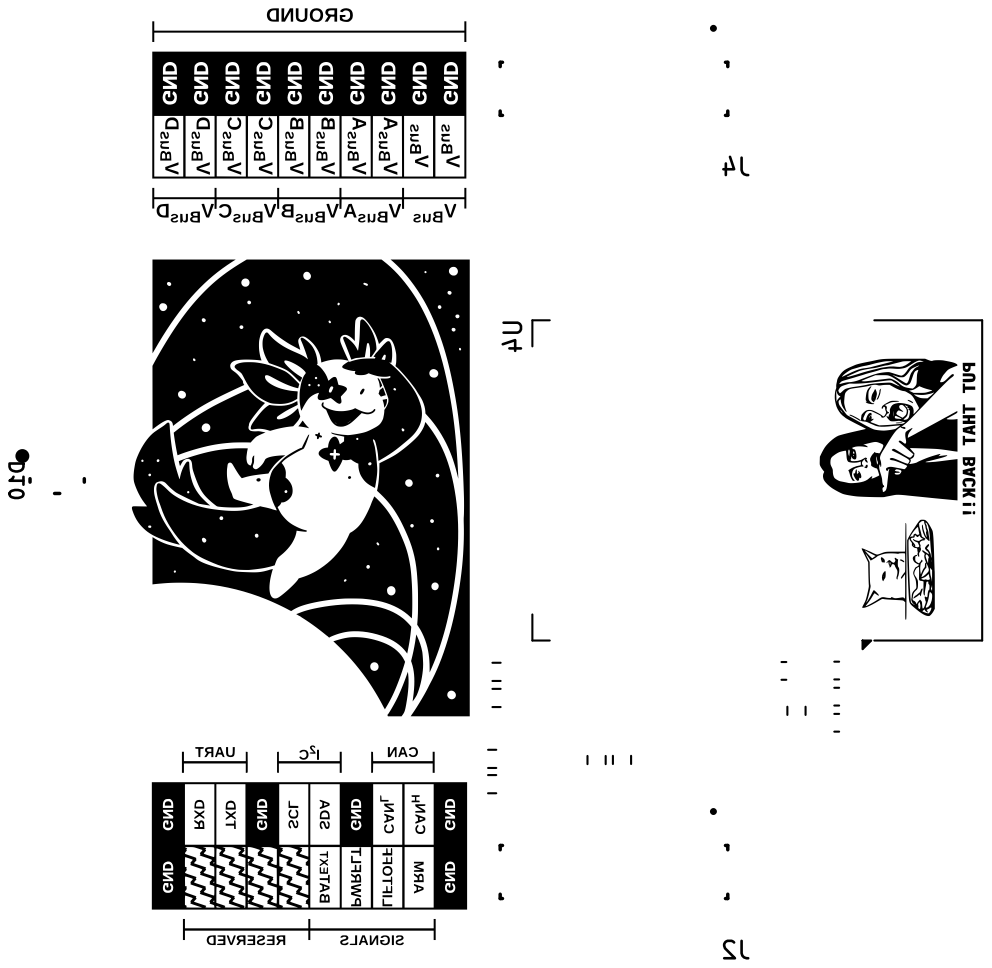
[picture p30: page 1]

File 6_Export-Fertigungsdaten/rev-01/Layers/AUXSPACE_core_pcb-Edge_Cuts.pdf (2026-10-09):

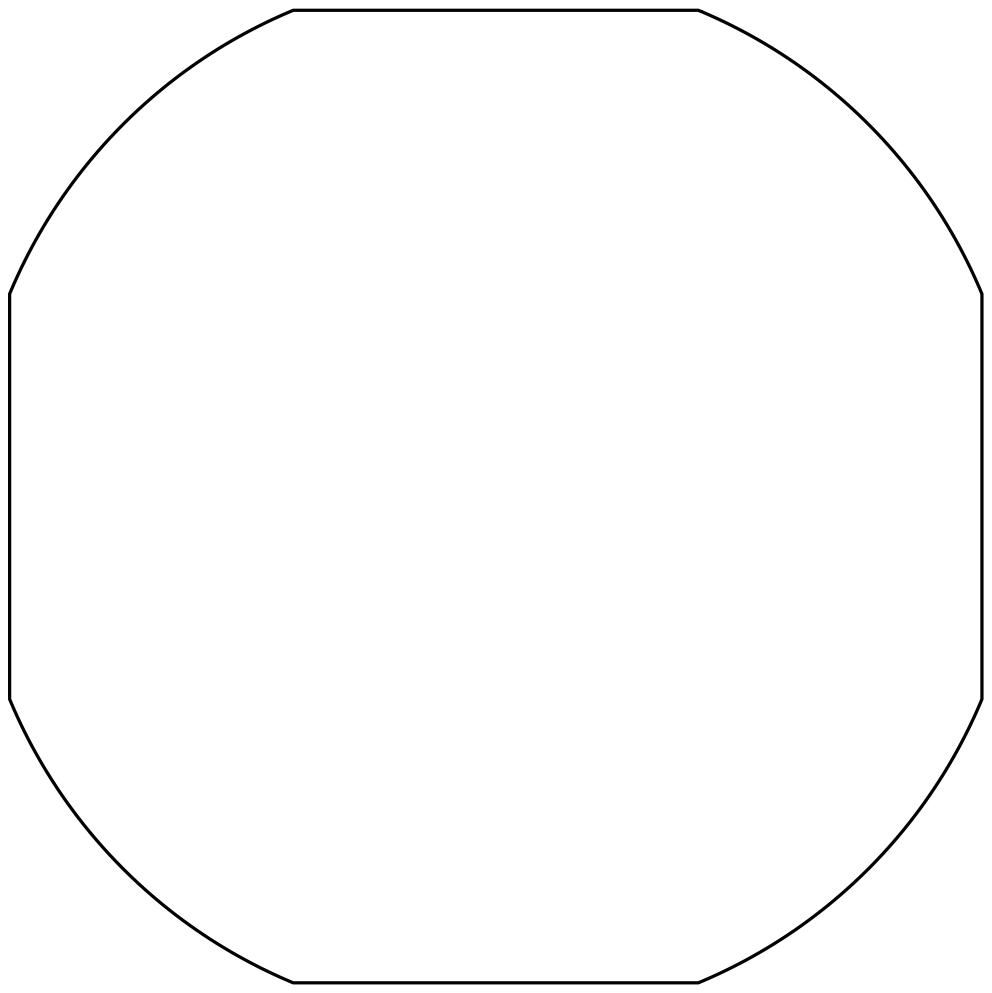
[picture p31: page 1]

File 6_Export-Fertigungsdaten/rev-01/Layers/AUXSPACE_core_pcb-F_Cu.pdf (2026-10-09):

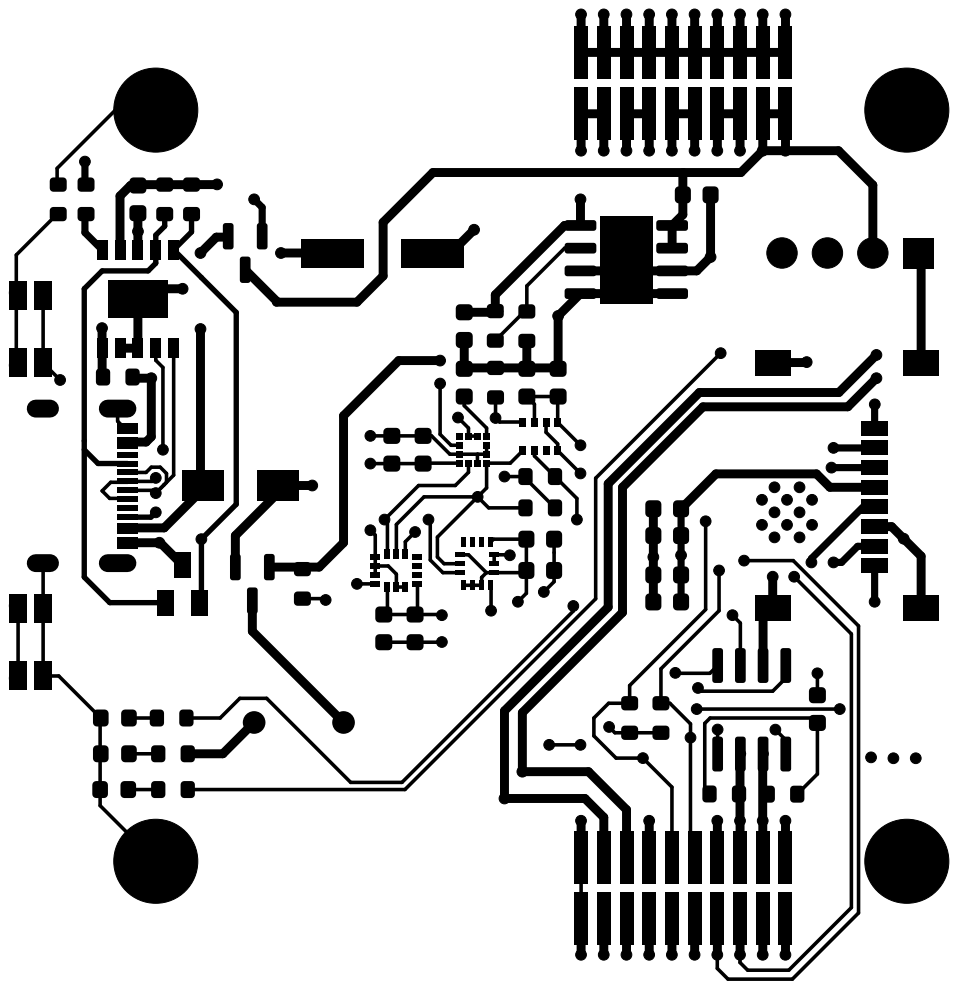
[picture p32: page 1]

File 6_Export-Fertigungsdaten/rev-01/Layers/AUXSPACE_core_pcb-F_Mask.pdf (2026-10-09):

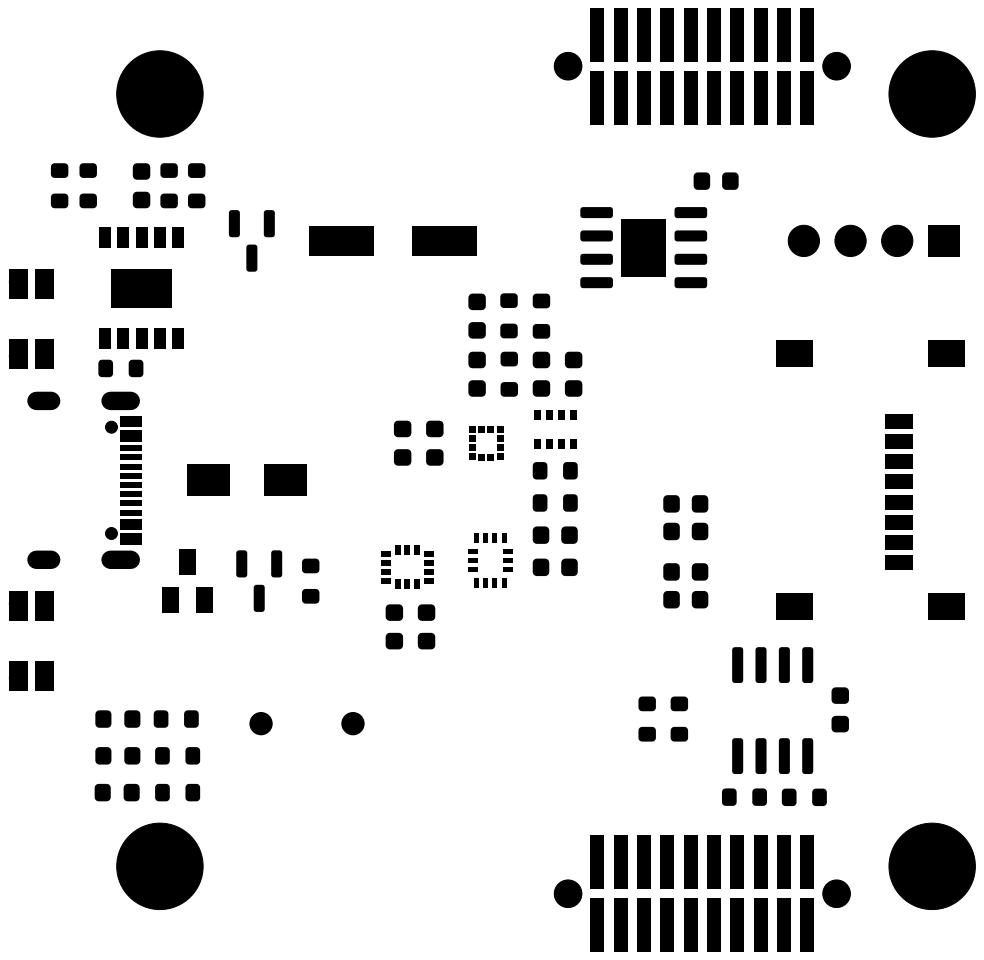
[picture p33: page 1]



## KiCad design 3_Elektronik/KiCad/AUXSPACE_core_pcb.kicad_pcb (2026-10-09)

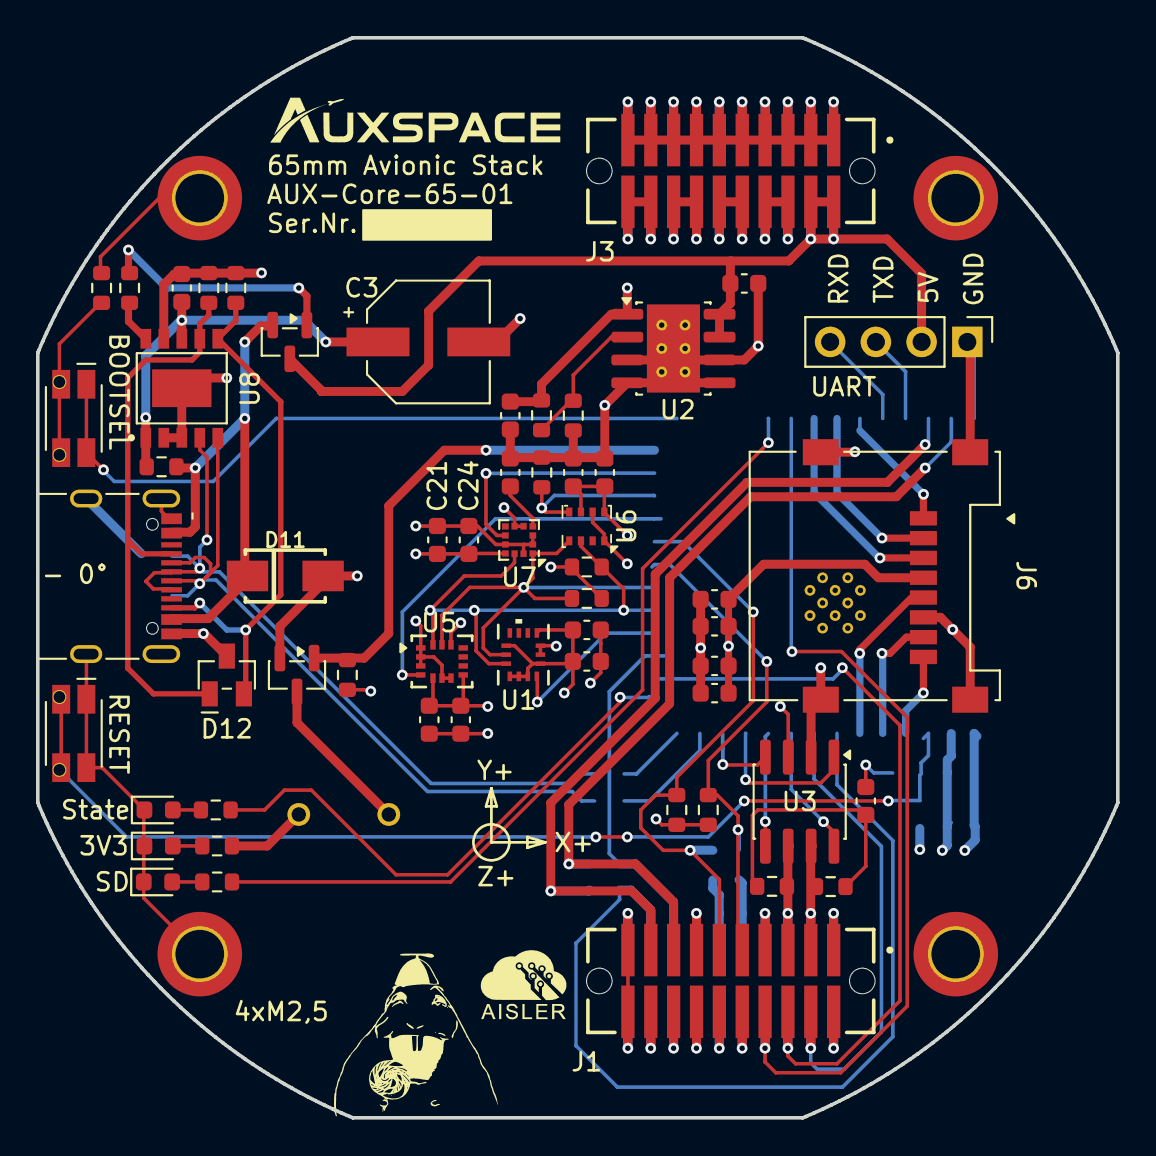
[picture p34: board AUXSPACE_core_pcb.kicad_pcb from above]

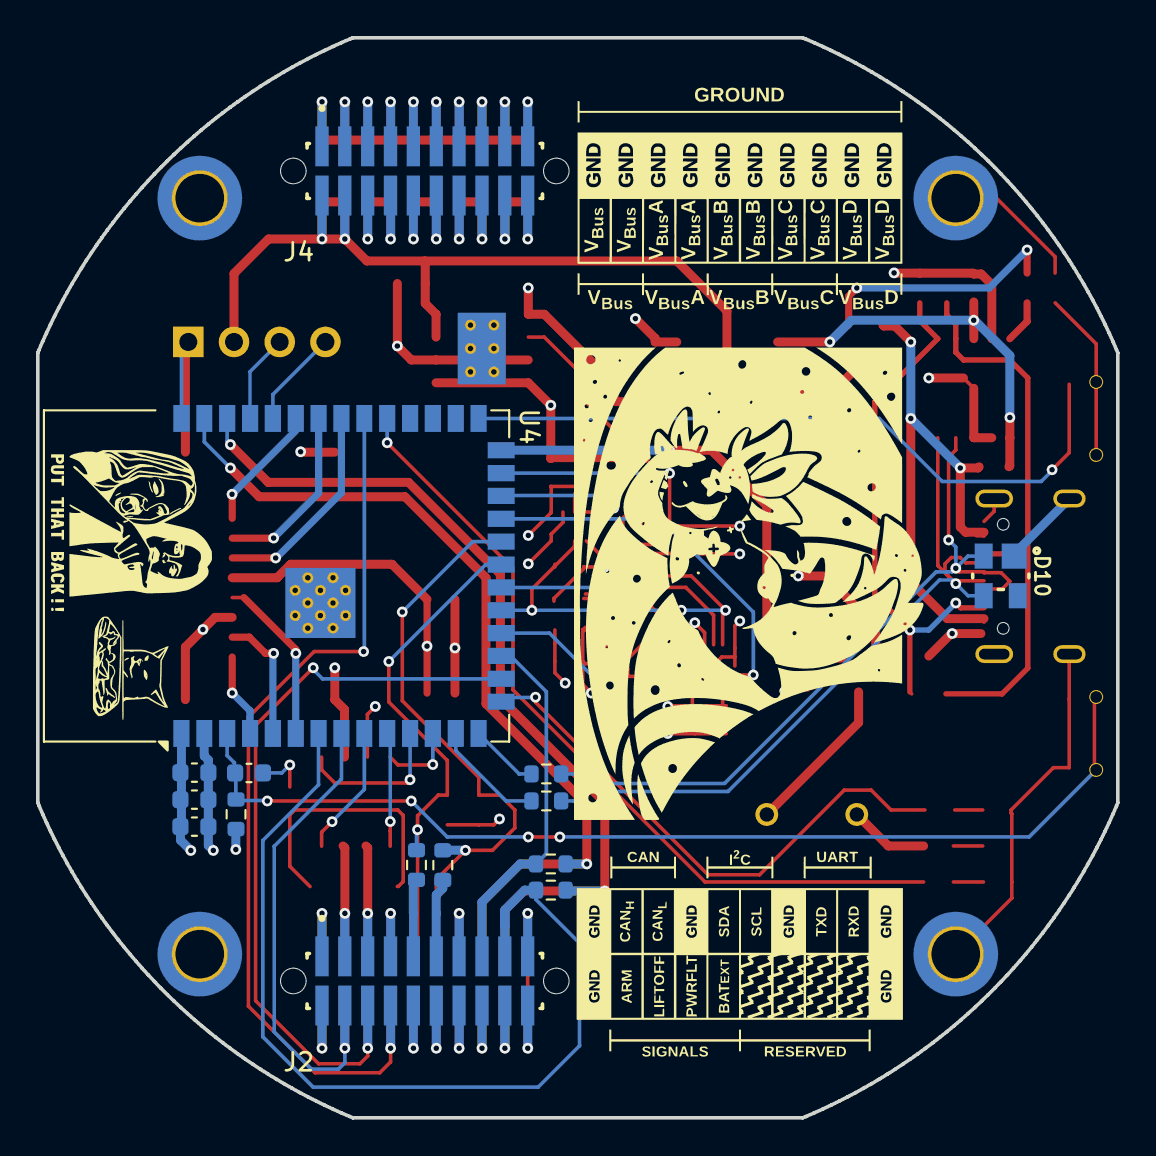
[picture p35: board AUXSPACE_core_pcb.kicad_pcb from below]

Board: 4 copper layers, 60.0 x 60.0 mm, 80 parts (15 on the bottom side), 66 nets.

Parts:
BZ1: WST-0904T; Buzzer_WST-0906T
C3: 150 µF; CP_Wurth_WCAP-ASLL-D6.3L5.5
C4, C5, C6, C8, C9, C11, C12, C13, C14, C16, C18, C20, C22, C23, C24: 100nF; C_0603_1608Metric
C7, C15: 10µF; C_0603_1608Metric
C10, C17, C19, C21: 1µF; C_0603_1608Metric
D3, D4, D5: grün; LED_0603_1608Metric
D10: 8240136; WE-TVS_SOT143-4L
D11: SMAJ22A; WE-TVS_SMAJ22A
D12: 824094024; WE-TVS_824094024_SOT23-3L
H1, H2, H3, H4: MountingHole_Pad; MountingHole_2.7mm_M2.5_DIN965_Pad_TopBottom
J1, J3: Conn_02x10_Odd_Even; SAMTEC_TFM-110-02-S-D-A
J2, J4: Conn_02x10_Odd_Even; SAMTEC_SFM-110-02-L-D-A-P-TR
J5: Conn_01x04_Pin; PinHeader_1x04_P2.54mm_Vertical
J6: 693072010801; J_Wurth_WR-CRD_693072010801
J7: 629722000214; J_Wurth_WR-USB_629722000214
Logo1: aisler_logo_5mm
Logo2, Logo2#2: AUXSPACE_Logo_2_5mm
Q1, Q2: 2N7002K; SOT-23
R1, R3, R5, R7: 0R; R_0603_1608Metric
R2, R17: 62R; R_0603_1608Metric
R4, R15: 11k; R_0603_1608Metric
R6: 2,7k; R_0603_1608Metric
R9, R10, R11, R14, R16, R23: 4,7k; R_0603_1608Metric
R12, R34: 10k; R_0603_1608Metric
R18, R21, R22: 390R; R_0603_1608Metric
R19, R20: 22R; R_0603_1608Metric
R30, R33: 5,1k; R_0603_1608Metric
R32: 100k; R_0603_1608Metric
SW2, SW3: 434331013822; SW_Wurth_WS-TASU_434331013822
U1: LSM6DSV320XTR; LGA-14L_2p5X3X0p83_STM
U2: TPS7B8601QDDARQ1; Texas_R-PDSO-G8_EP2.95x4.9mm_Mask2.4x3.1mm_ThermalVias
U3: TCAN334; SOIC-8_3.9x4.9mm_P1.27mm
U4: ESP32-S3-WROOM-1
U5: LSM6DSO32XTR; LGA_O32XTR_STM
U6: DPS310
U7: LIS3MDL; LGA-12_2x2mm_P0.5mm
U8: CH224A; ESSOP-10-1EP_3.9x5.0mm_P1mm_EP2.1x3.3mm

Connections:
+3V3: BZ1.1 (+), C5.1, C6.1, C7.2, C8.2, C9.1, C10.1, C11.2, C12.1, C14.1, C15.1, C17.1, C18.1, C21.1, C22.2, C23.2, C24.1, J6.4 (VDD), R4.1, R9.2, R10.2, R14.2, R15.1, R16.2, R18.2, U1.1 (SDO/TA0), U1.2 (SDX), U1.3 (SCX), U1.5 (VDDIO), U1.8 (VDD), U1.12 (CS), U2.1 (OUT), U3.3 (VCC), U4.2 (3V3), U5.5 (Vdd_IO), U5.8 (Vdd), U5.12 (CS), U6.6 (VDDIO), U6.8 (VDD), U7.5 (Vdd), U7.6 (Vdd_IO), U7.10 (~CS)
/Baseboard/ACCEL_INT1: U1.4 (INT1), U4.18 (IO10)
/Baseboard/ARM: J1.4, J2.4, U4.8 (IO15)
/Baseboard/BARO_INT: R12.2, U4.24 (IO47), U6.5 (SDO)
/Baseboard/Bat on ext: J1.10, J2.10
/Baseboard/Buzzer: Q1.1 (G), R11.1, U4.26 (IO45)
/Baseboard/CAN_H: J1.3, J2.3, R2.1, U3.7 (CANH)
/Baseboard/CAN_L: J1.5, J2.5, R17.2, U3.6 (CANL)
/Baseboard/CAN_RXD: U3.4 (RXD), U4.12 (IO8)
/Baseboard/CAN_SHDN: U3.5 (SHDN), U4.10 (IO17)
/Baseboard/CAN_STB: U3.8 (STB), U4.9 (IO16)
/Baseboard/CAN_TXD: U3.1 (TXD), U4.11 (IO18)
/Baseboard/CC1: D12.1 (I/O1), J7.A5 (CC1), R33.1, U8.7 (CC1)
/Baseboard/CC2: D12.2 (I/O2), J7.B5 (CC2), R30.1, U8.6 (CC2)
/Baseboard/I2C0_SCL: R9.1, U1.13 (SCL), U4.20 (IO12), U5.13 (SCL), U6.4 (SCK/SCL), U7.1 (SCL/SPC)
/Baseboard/I2C0_SDA: R10.1, U1.14 (SDA), U4.19 (IO11), U5.14 (SDA), U6.3 (SDI/SDA), U7.11 (SDA/SDI/SDO)
/Baseboard/I2C_SCL_bot: J2.11, R5.1
/Baseboard/I2C_SCL_top: J1.11, R5.2, R14.1, U4.22 (IO14)
/Baseboard/I2C_SDA_bot: J2.9, R7.1
/Baseboard/I2C_SDA_top: J1.9, R7.2, R16.1, U4.21 (IO13)
/Baseboard/IMU_INT: U4.23 (IO21), U5.4 (INT1)
/Baseboard/IO0: SW3.1, SW3.2, U4.27 (IO0)
/Baseboard/LIFTOFF: J1.6, J2.6, U4.16 (IO46)
/Baseboard/MAG_DRDY: U4.25 (IO48), U7.8 (DRDY)
/Baseboard/Power Fault: J1.8, J2.8, U4.32 (IO39)
/Baseboard/RX: J5.4, U4.36 (RXD0)
/Baseboard/SD_CD/DAT3_CS: J6.2 (CD/DAT3), U4.34 (IO41)
/Baseboard/SD_CLK: J6.5 (CLK), U4.6 (IO6)
/Baseboard/SD_CMD_MOSI: J6.3 (CMD), U4.33 (IO40)
/Baseboard/SD_DAT0_MISO: J6.7 (DAT0), U4.5 (IO5)
/Baseboard/SD_DAT1: J6.8 (DAT1), U4.4 (IO4)
/Baseboard/SD_DAT2: J6.1 (DAT2), U4.35 (IO42)
/Baseboard/SD_LED: R22.2, U4.31 (IO38)
/Baseboard/STATE_LED: R21.2, U4.15 (IO3)
/Baseboard/TX: J5.3, U4.37 (TXD0)
/Baseboard/UART_RX_bot: J2.17, R1.1, U4.7 (IO7)
/Baseboard/UART_RX_top: J1.17, R1.2, U4.38 (IO2)
/Baseboard/UART_TX_bot: J2.15, R3.1, U4.17 (IO9)
/Baseboard/UART_TX_top: J1.15, R3.2, U4.39 (IO1)
/Baseboard/USB_D+: D10.2, J7.A6 (D+1), J7.B6 (D+2), R20.1, U8.4 (DP)
/Baseboard/USB_D-: D10.3, J7.A7 (D-1), J7.B7 (D-2), R19.1, U8.5 (DM)
/Baseboard/VBus_switched_A: J3.6, J3.8, J4.6, J4.8
/Baseboard/VBus_switched_B: J3.10, J3.12, J4.10, J4.12
/Baseboard/VBus_switched_C: J3.14, J3.16, J4.14, J4.16
/Baseboard/VBus_switched_D: J3.18, J3.20, J4.18, J4.20
/Baseboard/reserved_1: J1.12, J2.12
/Baseboard/reserved_2: J1.14, J2.14
/Baseboard/reserved_3: J1.16, J2.16
/Baseboard/reserved_4: J1.18, J2.18
GND: C3.2, C4.2, C5.2, C6.2, C7.1, C8.1, C9.2, C10.2, C11.1, C12.2, C13.2, C14.2, C15.2, C16.1, C17.2, C18.2, C19.1, C20.1, C21.2, C22.1, C23.1, C24.2, D3.1 (K), D4.1 (K), D5.1 (K), D10.1, D11.2, D12.3 (GND), H1.1 (1_1), H2.1 (1_1), H3.1 (1_1), H4.1 (1_1), J1.1, J1.2, J1.7, J1.13, J1.19, J1.20, J2.1, J2.2, J2.7, J2.13, J2.19, J2.20, J3.1, J3.3, J3.5, J3.7, J3.9, J3.11, J3.13, J3.15, J3.17, J3.19, J4.1, J4.3, J4.5, J4.7, J4.9, J4.11, J4.13, J4.15, J4.17, J4.19, J5.1, J6.6 (VSS), J6.S1 (SHIELD), J6.S2 (SHIELD), J6.S3 (SHIELD), J6.S4 (SHIELD), J7.A1 (GND), J7.A12 (GND1), J7.B1 (GND3), J7.B12 (GND2), J7.S1 (SHIELD), J7.S2 (SHIELD), J7.S3 (SHIELD), J7.S4 (SHIELD), Q1.2 (S), R6.2, R11.2, R12.1, R23.1, R30.2, R33.2, SW2.1, SW2.2, U1.6 (GND), U1.7 (GND), U2.3 (NC), U2.4 (NC), U2.5 (GND), U2.6 (NC), U2.9 (Thermal_Pad), U3.2 (GND), U4.1 (GND), U4.40 (GND), U4.41 (GND), U5.1 (SDO/SA0), U5.2 (SDx), U5.3 (SCx), U5.6 (GND), U5.7 (GND), U6.1 (GND), U6.7 (GND), U7.2 (GND), U7.3 (GND), U7.9 (SDO/SA1), U7.12 (GND), U8.2 (CFG2/SCL), U8.3 (CFG3/SDA), U8.9 (CFG1), U8.11 (GND)
unnamed: BZ1.2 (-), Q1.3 (D)
unnamed: C16.2, R2.2, R17.1
unnamed: D3.2 (A), R18.1
unnamed: D4.2 (A), R21.1
unnamed: D5.2 (A), R22.1
unnamed: Q2.1 (G), R34.2
unnamed: R23.2, SW3.3, SW3.4, SW3.5, SW3.6
unnamed: R4.2, R6.1, U2.2 (FB)
unnamed: C13.1, R15.2, SW2.3, SW2.4, SW2.5, SW2.6, U4.3 (EN)
unnamed: R20.2, U4.14 (USB_D+)
unnamed: R19.2, U4.13 (USB_D-)
unnamed: C20.2, U7.4 (C1)
unnamed: R34.1, U8.10 (PG)
unnamed: C3.1, C19.2, R32.2, U8.1 (VHV), U8.8 (VBUS)
VBus_direct: C4.1, J3.2, J3.4, J4.2, J4.4, J5.2, Q2.3 (D), U2.7 (EN), U2.8 (IN)
Vusb: D11.1, J7.A4 (VBUS), J7.A9 (VBUS1), J7.B4 (VBUS3), J7.B9 (VBUS2), Q2.2 (S), R32.1

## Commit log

2026-08-28 feat(electronics): :sparkles: add KiCad files
    [AUXSPACE_core_pcb.kicad_pcb, AUXSPACE_core_pcb.kicad_sch, Baseboard.kicad_sch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]
2026-08-28 style: :art: directory layout and OSS compliance
    [AUXSPACE_core_pcb.kicad_pcb, AUXSPACE_core_pcb.kicad_sch, Baseboard.kicad_sch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]
2026-08-29 electronics: :sparkles: add BOOTSEL
    [AUXSPACE_core_pcb.kicad_pcb, Baseboard.kicad_sch]
2026-08-29 chore: :art: add stack footprint to designs
2026-09-03 BOM: added missing datasheets, added missing partnumbers, corrected partnumbers circit diagram: adjusted values unified writing
    [AUXSPACE_core_pcb.kicad_sch, Baseboard.kicad_sch]
2026-09-07 added UART top/bottom and Liftoff cnonection to µC
    [AUXSPACE_core_pcb.kicad_pcb, AUXSPACE_core_pcb.kicad_sch, Aux-core.step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]
2026-09-07 improved Layout
    [AUXSPACE_core_pcb.kicad_pcb]
2026-09-07 exported BOM
2026-09-19 exported schematic
2026-10-07 ci: add kicad-ci pipeline
2026-10-07 ci: replace kicad-ci with KiBot
    kicad-ci ran in kicad:9.0, which cannot open this KiCad 10 project, and
    carried ~3.5k lines of unmaintained scripts. KiBot (kicad10_auto_full,
    pinned) now runs ERC/DRC with zone refill and builds gerbers, drill,
    fab zip, pick & place, BOM (CSV/HTML), iBoM, schematic/PCB PDFs, STEP
    and 3D renders. PRs additionally get schematic/PCB diff PDFs against the
    base branch. Tags v* attach outputs to a GitHub release.
    ERC/DRC errors don't stop output generation but still fail the job (-F).
2026-10-07 fix(pcb): :bug: update zones
    [AUXSPACE_core_pcb.kicad_pcb]
2026-10-07 ci: :wrench: update drc from kicad example
2026-10-08 fix: :bug: drc errors
    [AUXSPACE_core_pcb.kicad_pcb, Baseboard.kicad_sch, IST8310.step]
2026-10-08 fix: :bug: use LIS3MDL mag
    [AUXSPACE_core_pcb.kicad_pcb, Baseboard.kicad_sch]
2026-10-08 ci(drc): :green_heart: fix errors
    [AUXSPACE_core_pcb.kicad_pcb, AUXSPACE_core_pcb.kicad_sch, Baseboard.kicad_sch]
2026-10-09 feat: :sparkles: new switches
    [AUXSPACE_core_pcb.kicad_pcb, AUXSPACE_core_pcb.kicad_sch, Baseboard.kicad_sch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]
2026-10-09 feat: :sparkles: add auxolotl
    [AUXSPACE_core_pcb.kicad_pcb, Baseboard.kicad_sch]
2026-10-09 fix: :art: add missing 3d models
    [AUXSPACE_core_pcb.kicad_pcb]
2026-10-09 fix: :bug: USB PD being 5V
    USB PD is now set to 9V via I/O level configuration
    as described in chapter 5.2.2 and table 5-2 in the
    CH224A datasheet:
    | CFG1 | CFG2 | CFG3 | Voltage |
    |:----:|:----:|:---:-|--------:|
    | 0 | 0 | 0 | 9V |
    | 0 | 0 | 1 | 12V |
    | 0 | 1 | 1 | 20V |
    | 0 | 1 | 0 | 28V |
    | 1 | X | X | 5V |
    [AUXSPACE_core_pcb.kicad_pcb, Baseboard.kicad_sch]
2026-10-09 style: :art: cleanup pcb
    [AUXSPACE_core_pcb.kicad_pcb, Baseboard.kicad_sch]
2026-10-09 fix: :bug: keep out zone overlap
    [AUXSPACE_core_pcb.kicad_pcb]
2026-10-12 style: :art: split schematics into subpages
2026-10-13 fix: :bug: rename usb_pd to generic power schematic
2026-10-17 fix: move D11 in current path
    This commit also fixes the messed-up footprint of J1
2026-10-26 build: :wrench: update schematics

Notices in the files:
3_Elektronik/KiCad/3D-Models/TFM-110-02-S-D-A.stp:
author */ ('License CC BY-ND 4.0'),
